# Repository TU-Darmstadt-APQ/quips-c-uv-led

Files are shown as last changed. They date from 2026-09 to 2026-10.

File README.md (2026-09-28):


# QUIPS-C UV-LEDs PCB and Mounting Apparatus
UV-LEDs intended for QUIPS-C experiment, includes CAD-models of mount and PCB.\
Adsorption of Rubidium atoms on the vacuum chamber surfaces can lead to stray electric fields, negatively impacting the Rydberg transition. Ionisation by UV light aims to suppress this effect.

pcb-front
pcb-back
mount-frontal

Available Files
-------
This repository includes:
- FreeCAD-files containing the model for the mounting apparatus.
- KiCAD-files containing the PCB design housing the LEDs. Additional resources such as Gerber files will be added in the future.

Mounting Requirements
-------
The rectangular PCB is to be mounted via 2 M3-screws onto the aluminium mount. Heat transfer is maintained by thermal paste. The mount itself is fixated onto existing mounting posts attached to the QUIPS-C vacuum chamber.

Parts
-------
- LED: Luminus Devices SST-08-UV-A40H-F365-00 (5 pieces)
- Resistor: Vishay CRCW12184R02FKEKHP
- Connector: JST_PH_B2B-PH-K_1x02_P2.00mm_Vertical

Power Specifications
-------
LED specifications:
- central wavelength: **365 nm**
- absolute maximum forward current: **1 A**
- absolute maximum junction temperature: **100 °C**
- radiometric flux at 0.5A: **>810 mW**
- maximum forward voltage: **3.6 V**

Resistor specifications:
- resistance: **4 Ohm**
- maximum power: **3.5 W**

Overall design specifications:
- nominal operation at **20 V / 0.5A**, power draw: **10 W**
- total radiometrix flux: **~4 W**
- heating power: **~6 W**

License
-------
This work is released under the CERN-OHL-W.\
See [https://ohwr.org/cern_ohl_w_v2.pdf](https://ohwr.org/cern_ohl_w_v2.pdf) or the included LICENSE file for more information.

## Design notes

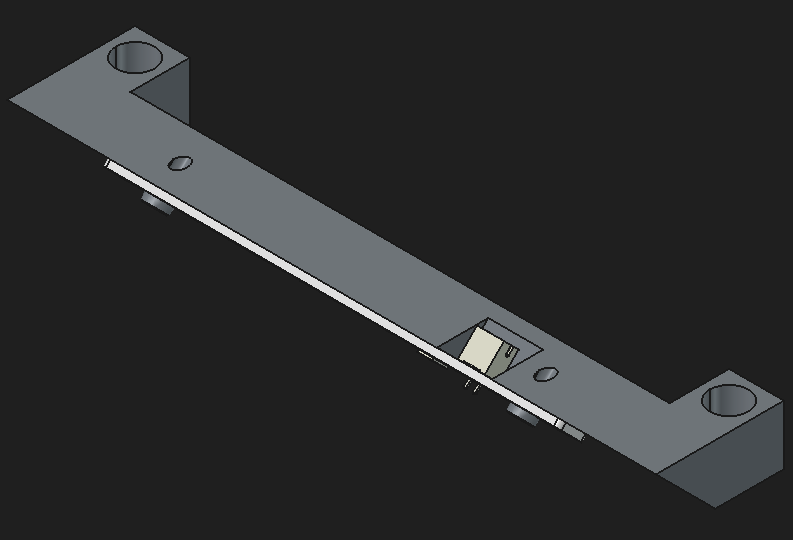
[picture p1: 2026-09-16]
freecad/images/mount1.png

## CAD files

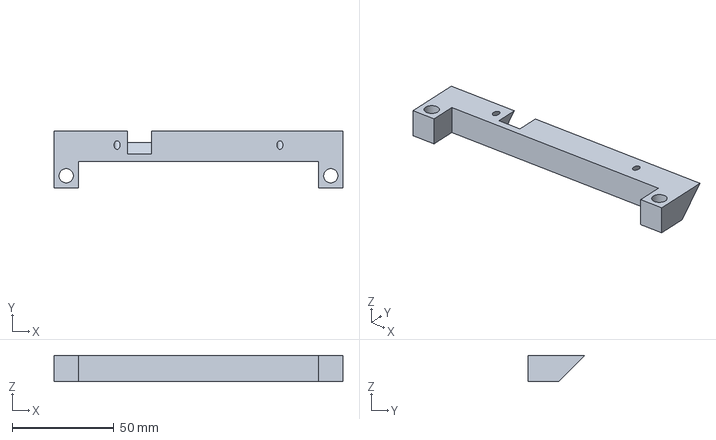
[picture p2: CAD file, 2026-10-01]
freecad/mount.FCStd
142.0 x 28.0 x 13.0 mm

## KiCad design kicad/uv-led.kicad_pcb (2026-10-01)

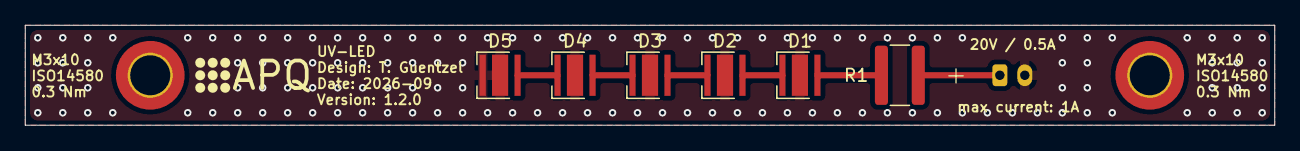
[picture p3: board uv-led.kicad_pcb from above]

Board: 2 copper layers, 100.0 x 8.0 mm, 10 parts (1 on the bottom side), 7 nets.

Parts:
D1, D2, D3, D4, D5: SST-08H; LED_Cree-XHP35
H1, H2: MountingHole_Pad; MountingHole_3.2mm_M3_ISO14580_Pad_TopOnly
J1: JST_PH_B2B-PH-K_1x02_P2.00mm_Vertical
LOGO1: Logo_APQ; APQ-Logo_small
R1: 4R; R_1218_3246Metric

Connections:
+20V: J1.1, R1.2
GND: D1.3 (PAD), D2.3 (PAD), D3.3 (PAD), D4.3 (PAD), D5.1 (K), D5.3 (PAD), J1.2
unnamed: D1.2 (A), R1.1
unnamed: D1.1 (K), D2.2 (A)
unnamed: D2.1 (K), D3.2 (A)
unnamed: D3.1 (K), D4.2 (A)
unnamed: D4.1 (K), D5.2 (A)

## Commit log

2026-08-28 moved files to kicad directory
    [uv-led.kicad_pcb, uv-led.kicad_sch]
2026-08-28 changed pcb core to aluminium
    [uv-led.kicad_pcb]
2026-08-28 added freecad models of mounting apparatus
    [uv-led-mount-30deg.FCStd, uv-led-mount-45deg-reclined.FCStd, uv-led-mount-45deg.FCStd]
2026-09-02 added screw specs to silkscreen (#3)
    [uv-led.kicad_pcb, uv-led.kicad_sch]
2026-09-02 added recommended voltage / current and max current (#4)
    [uv-led.kicad_pcb]
2026-09-02 added polarity marker (+) on front and back silkscreen (#5)
    [uv-led.kicad_pcb]
2026-09-02 removed back silkscreen and set B.Cu layer thickness to 0, stackup thickness of 1.6mm wanted (#6)
    [uv-led.kicad_pcb]
2026-09-02 added dimensions in user.drawings including PCB size and hole radius (#7), removed H indicators (#8)
    [uv-led.kicad_pcb]
2026-09-02 added logo and info on silkscreen (#9)
    [uv-led.kicad_pcb]
2026-09-02 added design infos to PCB and schematic (#11)
    [uv-led.kicad_pcb, uv-led.kicad_sch]
2026-09-02 added power and electrical details to schematic, updated silkscreen on PCB (#10)
    [uv-led.kicad_pcb, uv-led.kicad_sch]
2026-09-02 added operating temperatures and RoHs compliance of resistor and LEDs (#13)
    [uv-led.kicad_pcb, uv-led.kicad_sch]
2026-09-02 added images of PCB and modified readme accordingly (#2)
2026-09-04 removed obsolete freecad files
    [uv-led-mount-30deg.FCStd, uv-led-mount-45deg-reclined.FCStd, uv-led-mount-45deg.FCStd]
2026-09-04 added updated mount with simplified structure and screw cutouts
    [mount.FCStd]
2026-09-04 added images of mount
2026-09-04 added mount image in readme
2026-09-16 simplified mount and added technical drawing
    [mount.FCStd]
2026-09-17 changed screw type to M6 and increased revision to 1.1.0
    [mount.FCStd]
2026-09-17 added screw model for M6
    [mount.FCStd]
2026-09-18 updated revision number to 1.1.0
    [uv-led.kicad_pcb, uv-led.kicad_sch]
2026-09-22 updated revision number on PCB silkscreen
    [uv-led.kicad_pcb]
2026-09-23 added version label on silkscreen
    [uv-led.kicad_pcb]
2026-09-28 Feature/ci pipeline (#14)
    * initial addition of bom and kibot config
    * replaced bom and kibot config from one inch photodetector
    * added github workflows from one inch photodetector
    * removed back PCB layers
    * changed project files in ci.yml
    * moved .github to root
    * updated file paths in ci.yml
    * changed screw type to M6 and increased revision to 1.1.0
    * added screw model for M6
    * updated revision number to 1.1.0
    * updated revision number on PCB silkscreen
    * added version label on silkscreen
    * changed ordering of version label on silkscreen
    * added badge to readme
    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
    [uv-led.kicad_pcb, uv-led.kicad_sch]
2026-09-28 Fixed BOM (#18)
    - Fixed JST PN
    - Fixed LED temperature
    - Bumped to v1.1.1
    [uv-led.kicad_pcb, uv-led.kicad_sch]
2026-10-01 Feature/two layer PCB with vias (#19)
    * enlarged drill holes for M6 screws for more tolerance
    * updated mount revision number to 1.2.0
    * updated revision number to 1.2.0
    * updated PCB revision label
    * screw pads changed to unconnected
    * updated physical stackup to two 70um copper layers
    * Added missing infos
    - Missing dimension
    - Moved J1 label
    - Added board finish
    ---------
    [mount.FCStd, uv-led.kicad_pcb, uv-led.kicad_sch]

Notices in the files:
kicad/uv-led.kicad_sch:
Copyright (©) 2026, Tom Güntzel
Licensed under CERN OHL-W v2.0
